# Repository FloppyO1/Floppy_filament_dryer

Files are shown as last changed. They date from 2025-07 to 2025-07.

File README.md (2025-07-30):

# Floppy Filament Dryer
Descrizione 1
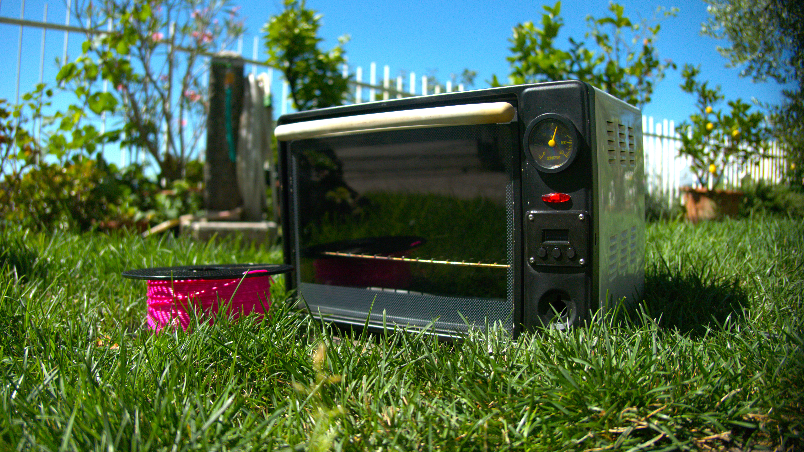
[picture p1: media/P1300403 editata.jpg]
Descrizione 2


This project is a controller board designed for a small electric oven, transforming it into a filament dryer for 3D printing. The controller allows precise temperature management, helping keep your filament dry and ready to use.

## Features

- Temperature control for effective filament drying
- Multiple materials presets
- Timer function
- Two custom material temp available
- Compatible with standard electric ovens
- Easy setup and integration

## YouTube Video

Watch it in action: [Filament Dryer Demo](https://youtu.be/55DRHrMC5Mg)

## License

This project is open source. See the LICENSE file for more details.

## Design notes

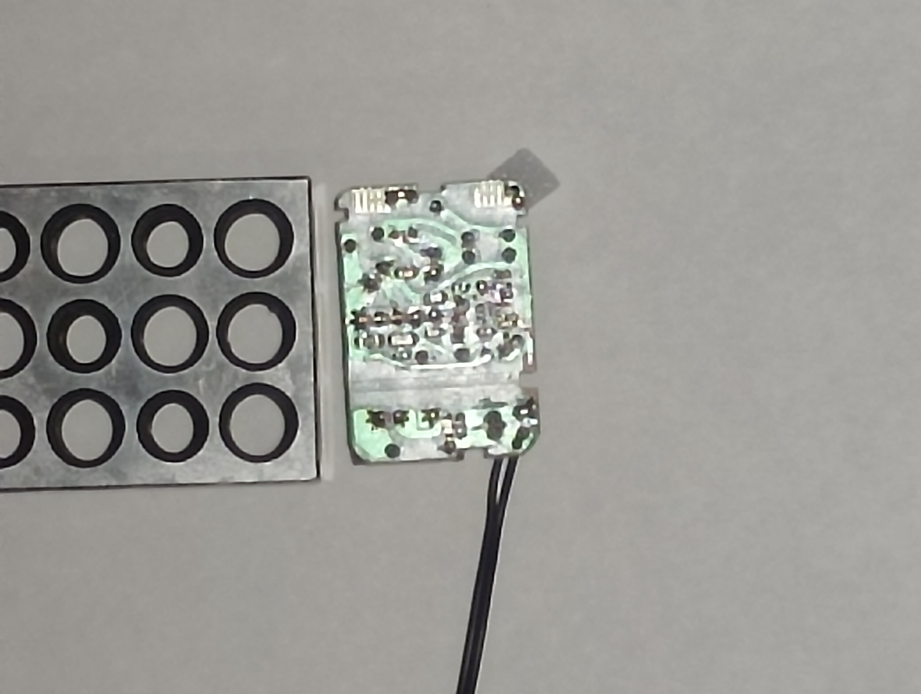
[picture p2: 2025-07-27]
CASE/case alimentatore 5v/ref image.jpg

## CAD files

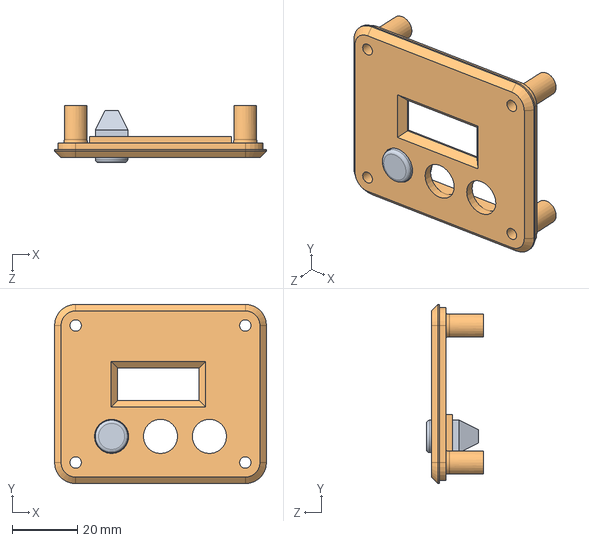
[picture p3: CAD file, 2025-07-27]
CASE/V1/Assieme.SLDASM
65.0 x 55.0 x 17.5 mm
Mascherina
button

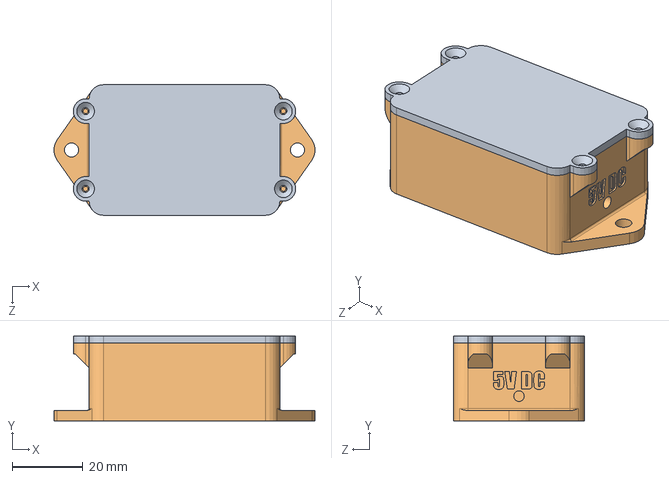
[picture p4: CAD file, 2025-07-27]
CASE/case alimentatore 5v/Assieme1.SLDASM
73.9 x 24.0 x 37.0 mm
CASE
COPERCHIO

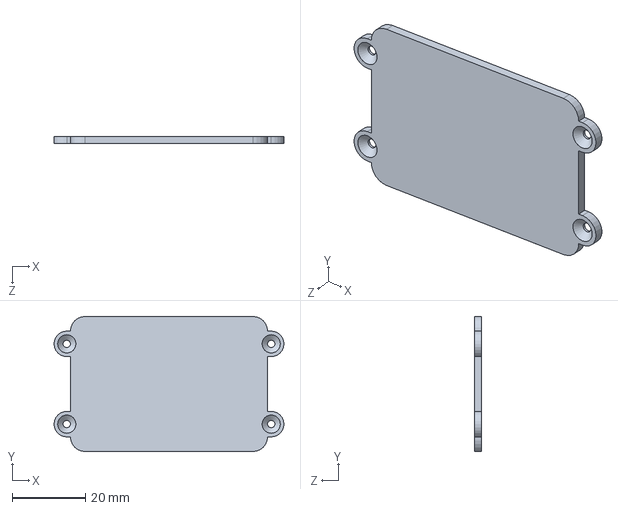
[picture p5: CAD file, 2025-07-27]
CASE/case alimentatore 5v/COPERCHIO.SLDPRT
63.0 x 37.0 x 2.00 mm

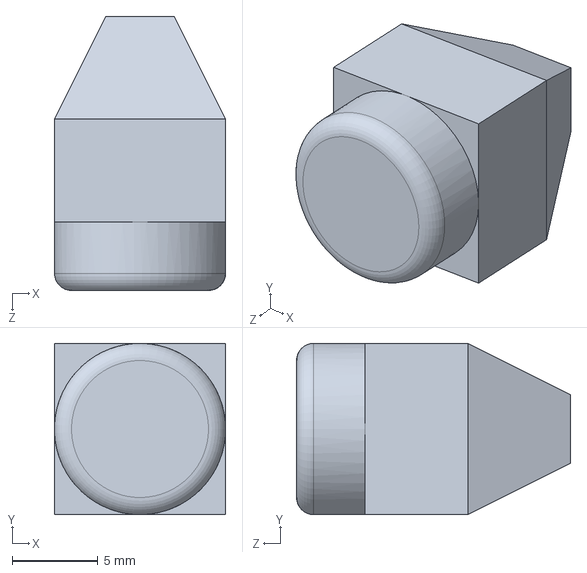
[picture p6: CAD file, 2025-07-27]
CASE/V1/button.SLDPRT
10.0 x 10.0 x 16.0 mm

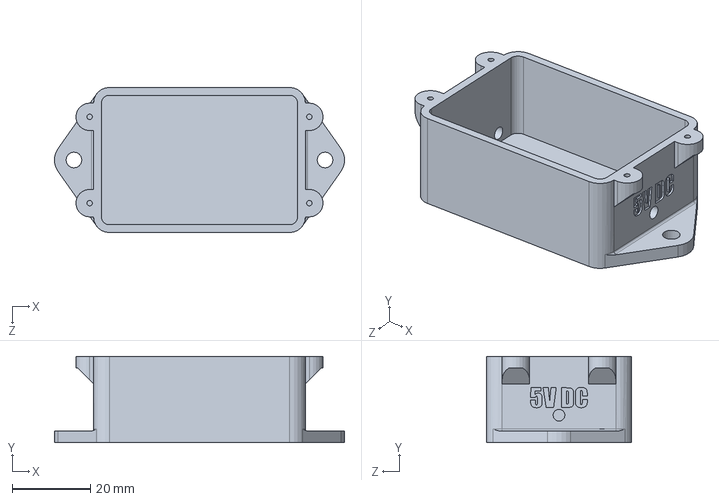
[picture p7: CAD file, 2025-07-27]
CASE/case alimentatore 5v/CASE.SLDPRT
73.9 x 22.0 x 37.0 mm

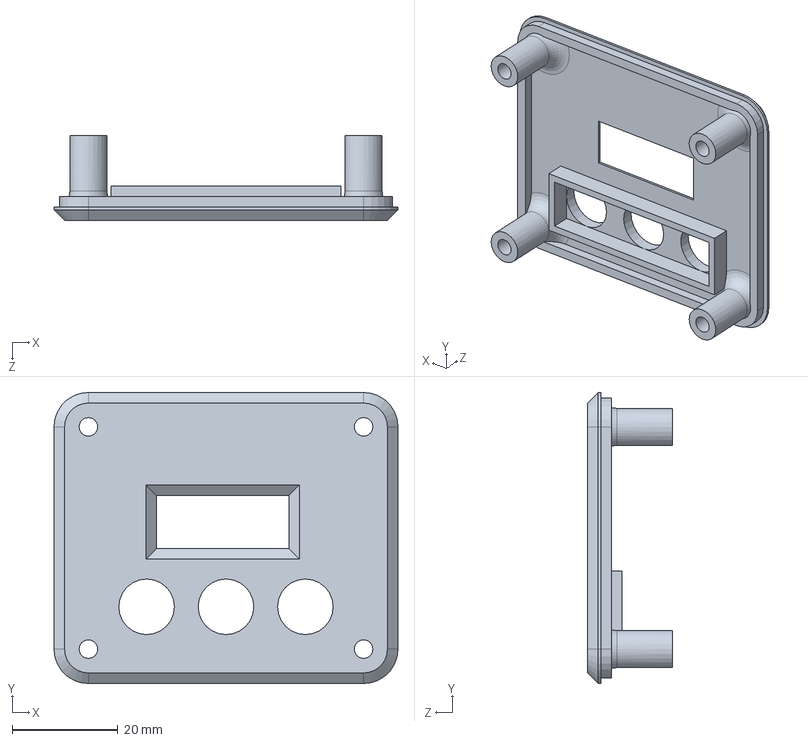
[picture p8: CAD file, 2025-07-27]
CASE/V1/Mascherina.SLDPRT
65.0 x 55.0 x 16.0 mm

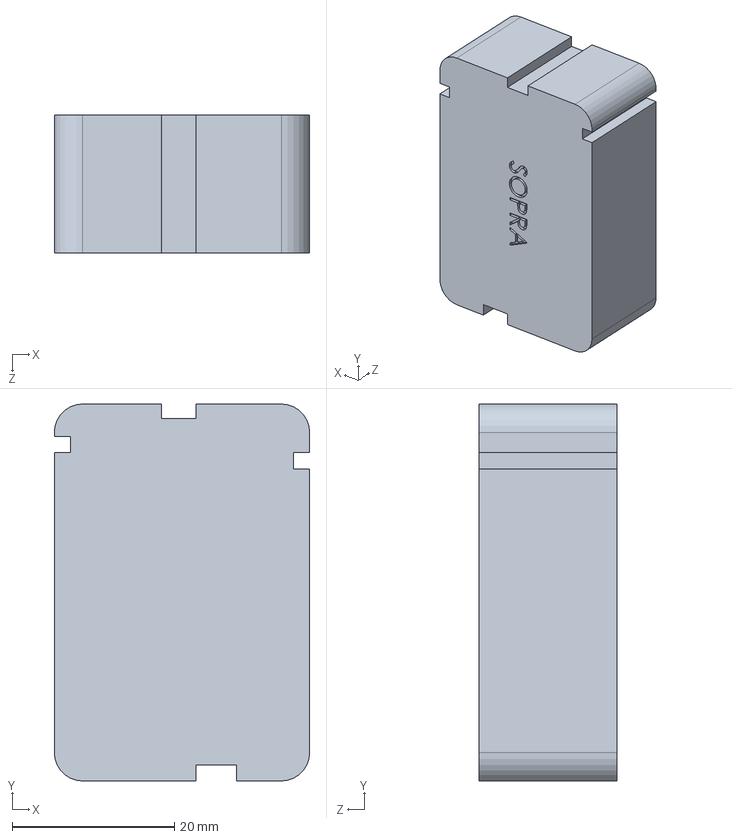
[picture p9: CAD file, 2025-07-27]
CASE/case alimentatore 5v/ingombro alimentatore.SLDPRT
31.5 x 46.5 x 17.0 mm

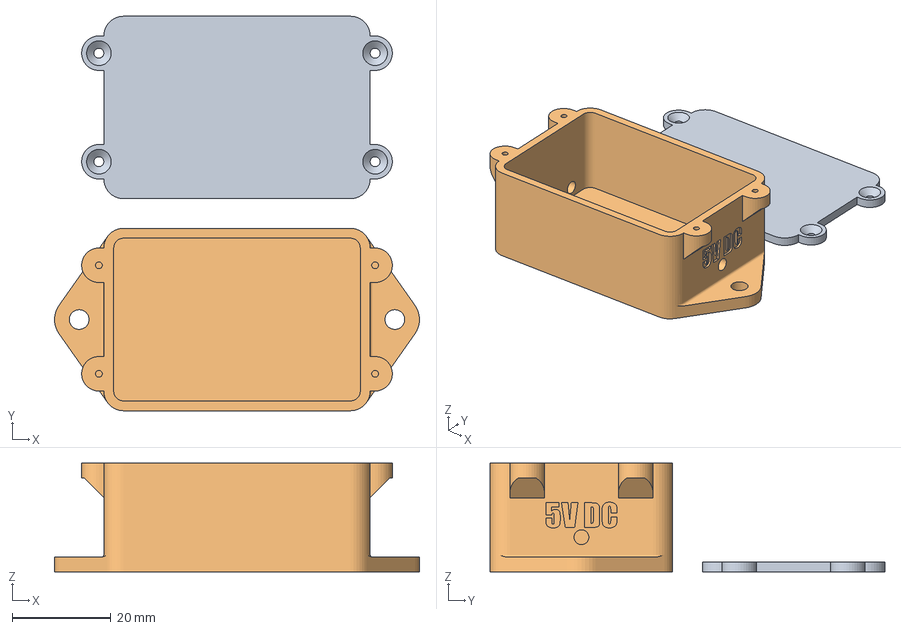
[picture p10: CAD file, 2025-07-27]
CASE/case alimentatore 5v/Scatoletta alimentatore 5v dc.3MF
74.0 x 80.0 x 22.0 mm

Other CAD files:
CASE/V1/Assieme.3MF

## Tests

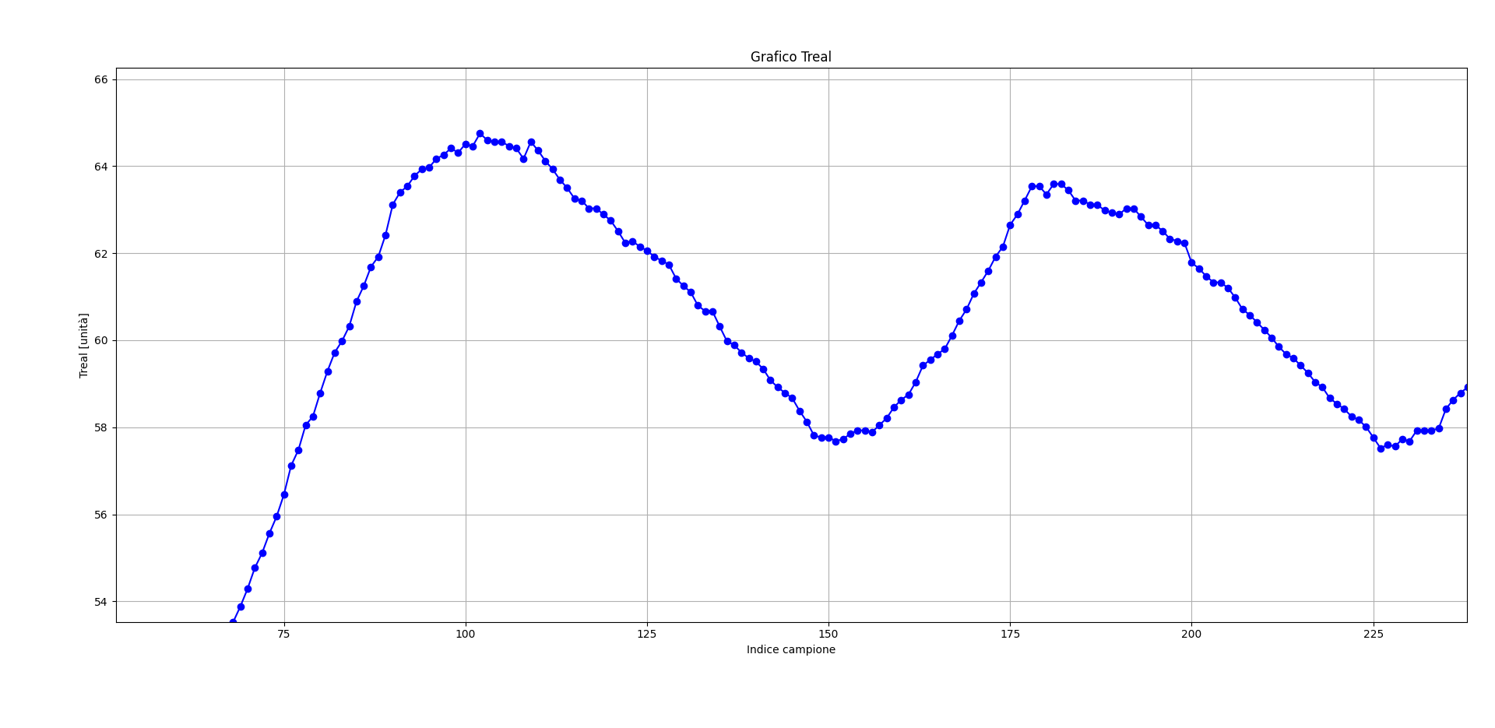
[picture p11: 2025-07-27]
SOFTWARE/Test autocalibrazione PID/Test 5/grafico zoom prime due oscillazioni.png

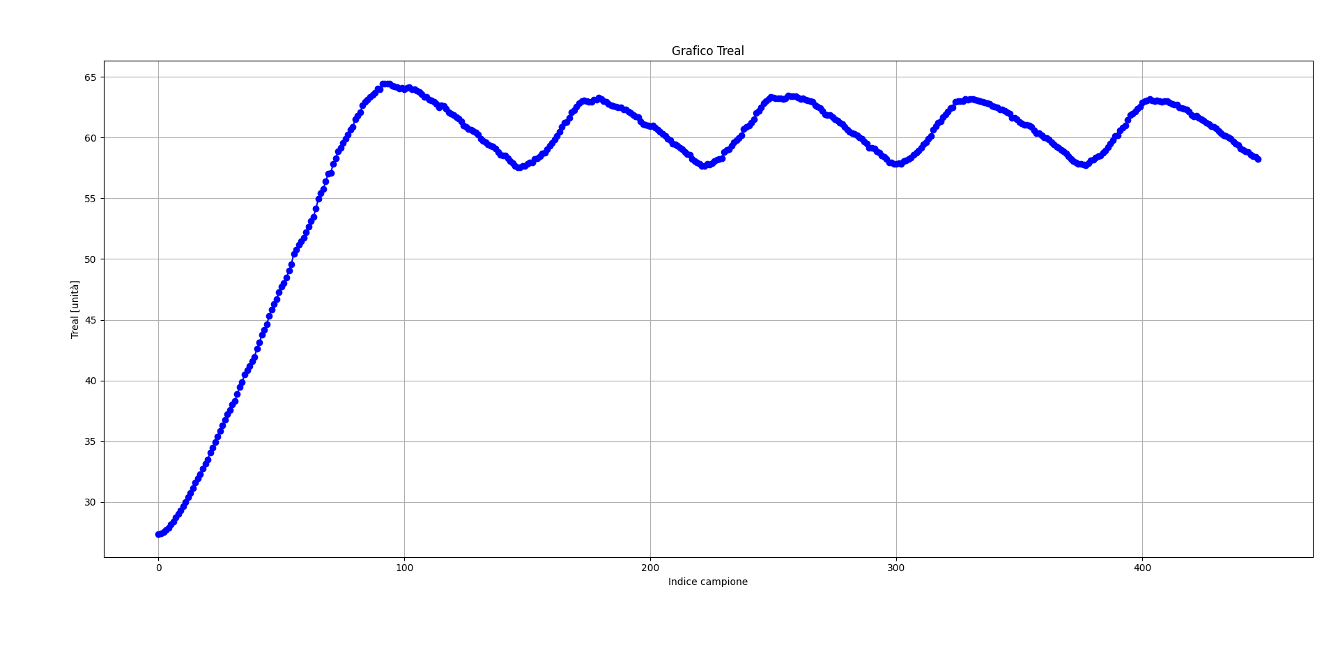
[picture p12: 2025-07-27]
SOFTWARE/Test autocalibrazione PID/Test 6/grafico completo.png

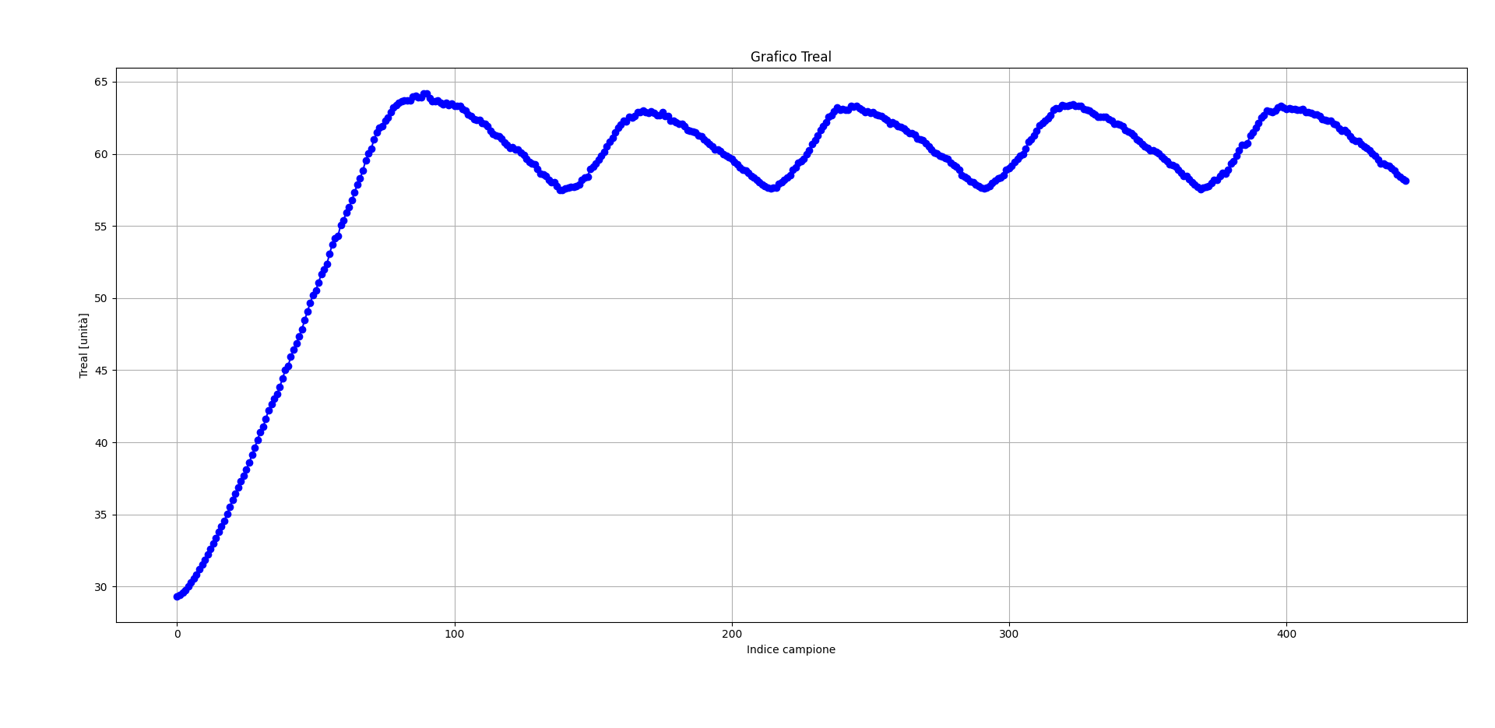
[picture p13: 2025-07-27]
SOFTWARE/Test autocalibrazione PID/Test 4/Figure_1.png

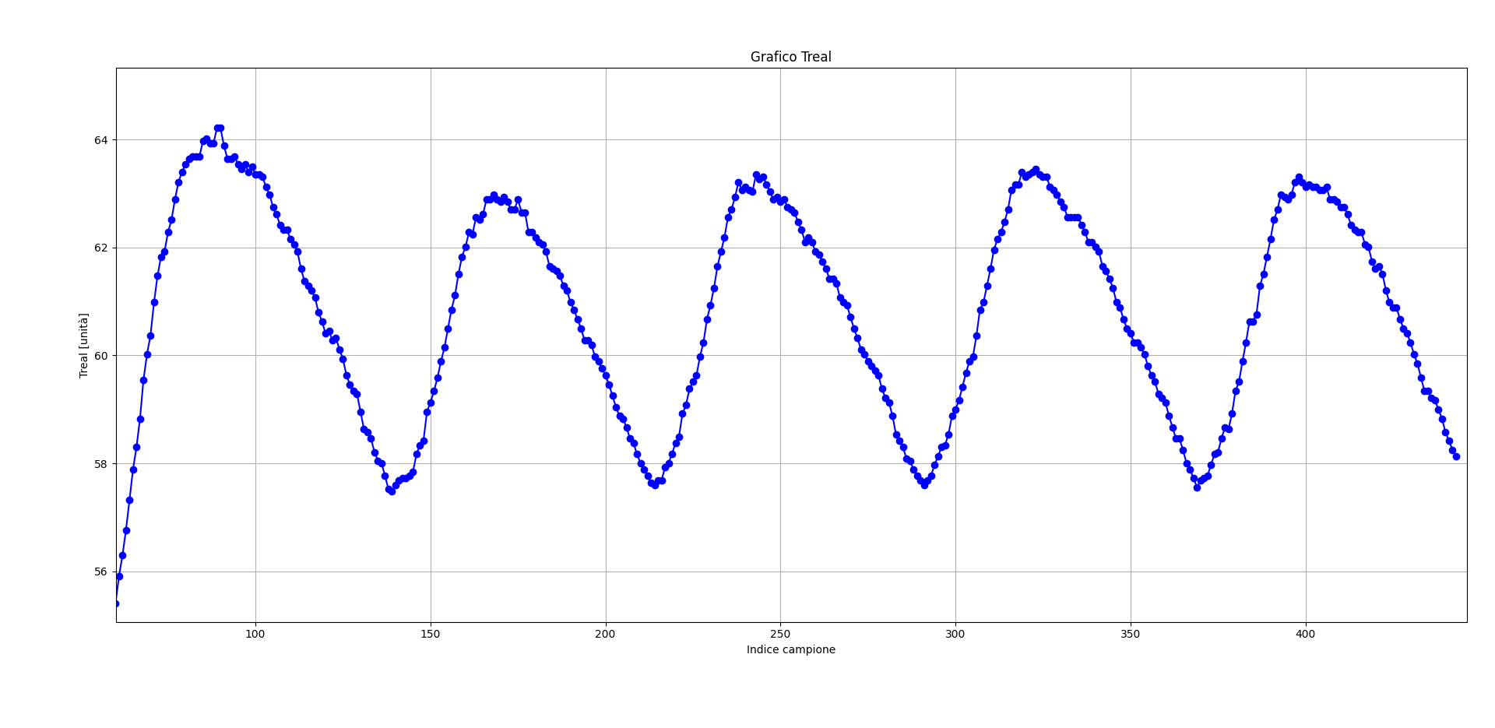
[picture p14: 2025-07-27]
SOFTWARE/Test autocalibrazione PID/Test 4/Figure_1 zoomed.png

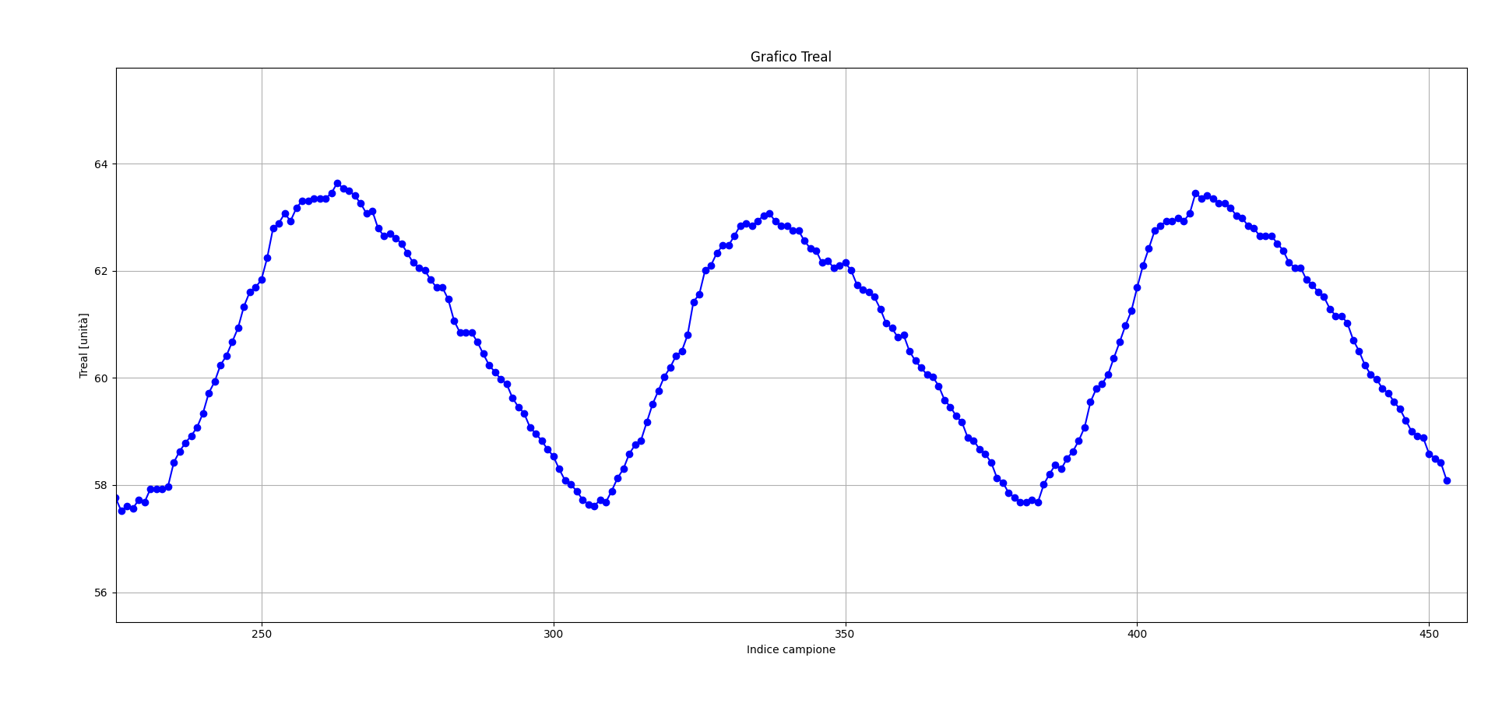
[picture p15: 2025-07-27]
SOFTWARE/Test autocalibrazione PID/Test 5/grafico zoom ultime 3 oscillazioni oscillazioni.png

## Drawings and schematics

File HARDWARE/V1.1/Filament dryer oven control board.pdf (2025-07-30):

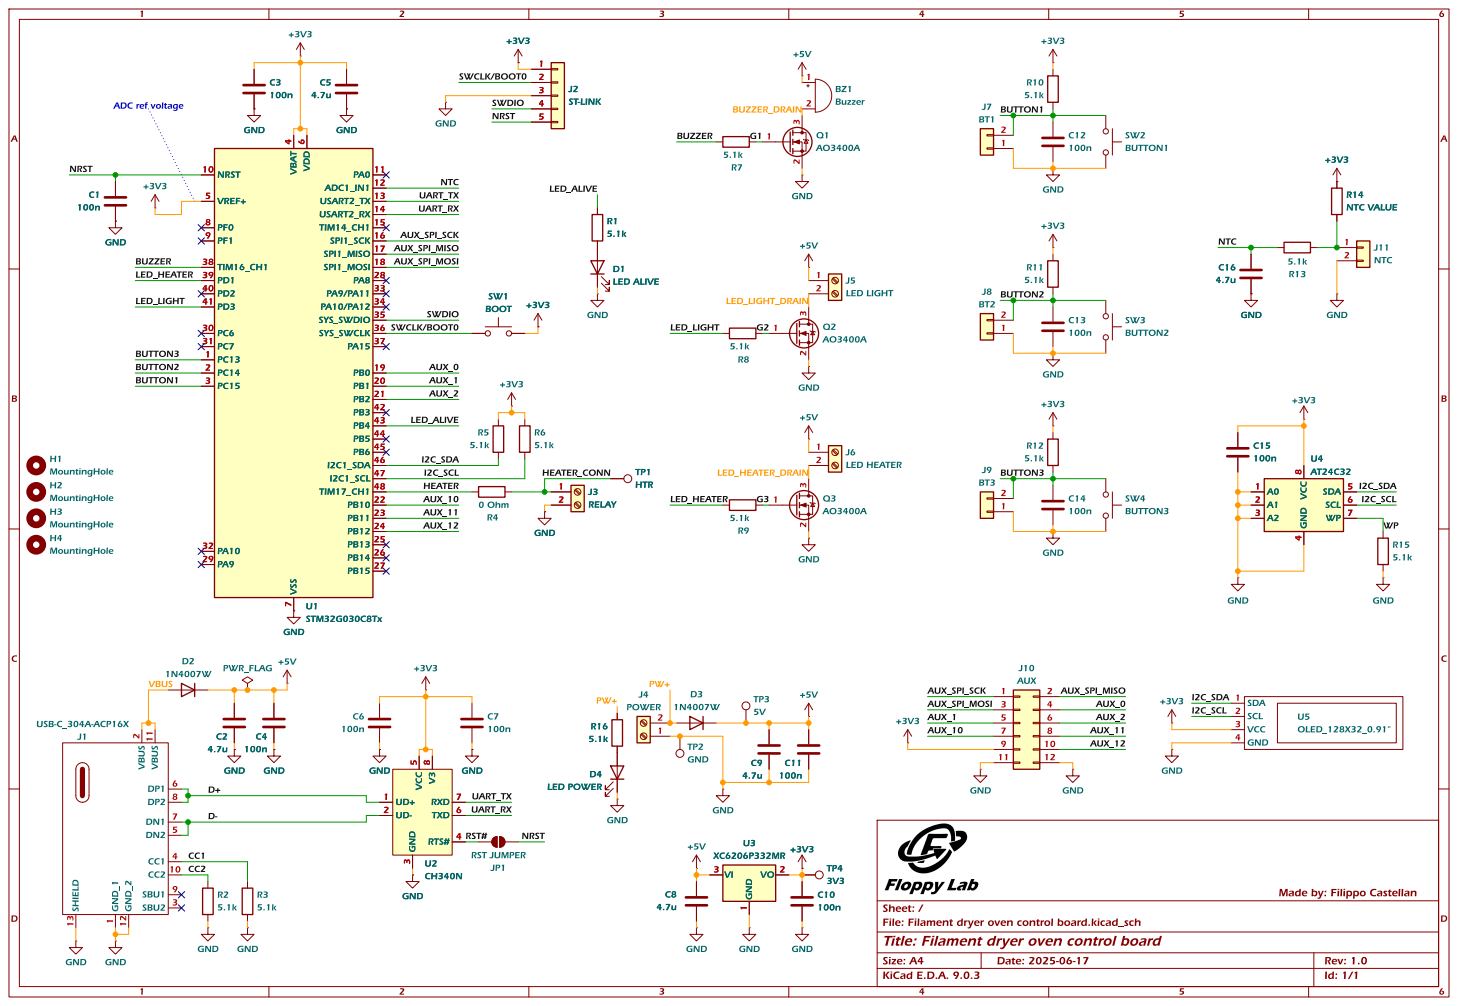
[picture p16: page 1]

Id: 1/1 Title: Filament dryer oven control board

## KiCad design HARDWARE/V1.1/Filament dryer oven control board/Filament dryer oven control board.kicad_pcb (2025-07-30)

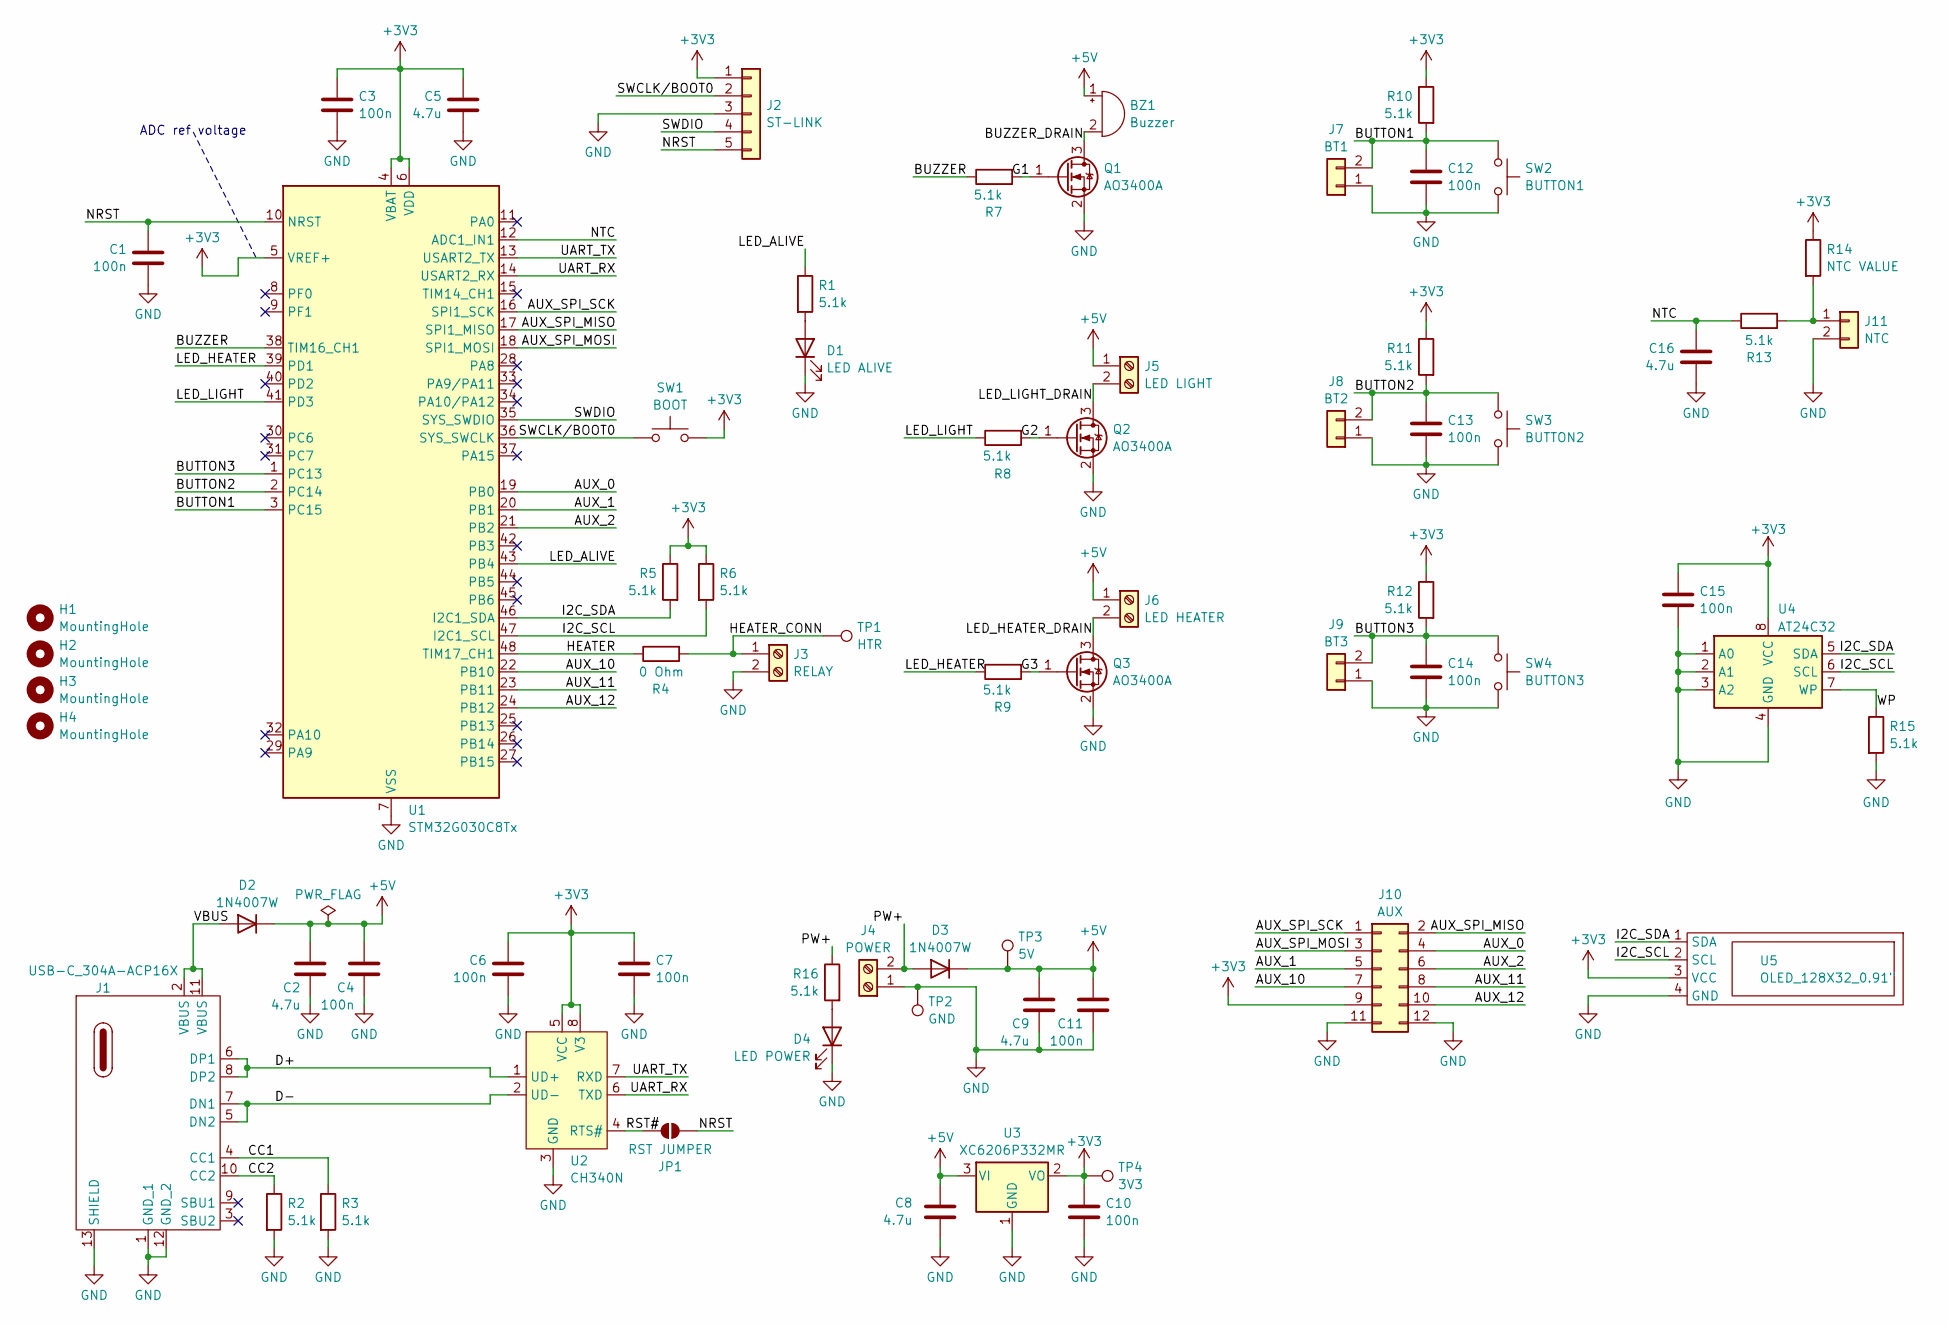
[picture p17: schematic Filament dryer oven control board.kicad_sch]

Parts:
BZ1: Buzzer; Buzzer_12x9.5RM7.6
C1, C3, C4, C6, C7, C10, C11, C12, C13, C14, C15: 100n; C_0805_2012Metric_Pad1.18x1.45mm_HandSolder
C2, C5, C8, C9, C16: 4.7u; C_0805_2012Metric_Pad1.18x1.45mm_HandSolder
D1: LED ALIVE; LED_0805_2012Metric_Pad1.15x1.40mm_HandSolder
D2, D3: 1N4007W; D_SOD-123F; LCSC C7528871
D4: LED POWER; LED_0805_2012Metric_Pad1.15x1.40mm_HandSolder
H1, H2, H3, H4: MountingHole; MountingHole_3.2mm_M3_Pad_Via
J1: USB-C_304A-ACP16X; USB_C_304A-ACP16X
J2: ST-LINK; PinHeader_1x05_P2.54mm_Vertical
J3: RELAY; TerminalBlock_bornier-2_P5.08mm
J4: POWER; TerminalBlock_bornier-2_P5.08mm
J5: LED LIGHT; TerminalBlock_bornier-2_P5.08mm
J6: LED HEATER; TerminalBlock_bornier-2_P5.08mm
J7: BT1; JST_XH_B2B-XH-A_1x02_P2.50mm_Vertical
J8: BT2; JST_XH_B2B-XH-A_1x02_P2.50mm_Vertical
J9: BT3; JST_XH_B2B-XH-A_1x02_P2.50mm_Vertical
J10: AUX; PinHeader_2x06_P2.54mm_Vertical
J11: NTC; JST_XH_B2B-XH-A_1x02_P2.50mm_Vertical
JP1: RST JUMPER; SolderJumper-2_P1.3mm_Open_RoundedPad1.0x1.5mm
Q1, Q2, Q3: AO3400A; SOT-23
R1, R2, R3, R5, R6, R7, R8, R9, R10, R11, R12, R13, R15, R16: 5.1k; R_0805_2012Metric_Pad1.20x1.40mm_HandSolder
R4: 0 Ohm; R_0805_2012Metric_Pad1.20x1.40mm_HandSolder
R14: NTC VALUE; R_0805_2012Metric_Pad1.20x1.40mm_HandSolder
SW1: BOOT; SW-SMD_TS24CA SMD BUTTO 90deg
SW2: BUTTON1; SW_SPST_SKQG_WithoutStem
SW3: BUTTON2; SW_SPST_SKQG_WithoutStem
SW4: BUTTON3; SW_SPST_SKQG_WithoutStem
TP1: HTR; TestPoint_THTPad_1.0x1.0mm_Drill0.5mm
TP2: GND; TestPoint_THTPad_1.0x1.0mm_Drill0.5mm
TP3: 5V; TestPoint_THTPad_1.0x1.0mm_Drill0.5mm
TP4: 3V3; TestPoint_THTPad_1.0x1.0mm_Drill0.5mm
U1: STM32G030C8Tx; LQFP-48_7x7mm_P0.5mm
U2: CH340N; SOP-8_3.9x4.9mm_P1.27mm
U3: XC6206P332MR; SOT-23-3
U4: AT24C32; SO-8_3.9x4.9mm_P1.27mm
U5: OLED_128X32_0.91"; PinSocket_1x04_P2.54mm_Vertical

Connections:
+3V3: C3.1, C5.1, C6.1, C7.1, C10.1, C15.1, J2.1, J10.9, R5.1, R6.1, R10.1, R11.1, R12.1, R14.1, SW1.2, TP4.1, U1.4 (VBAT), U1.5 (VREF+), U1.6 (VDD), U2.5 (VCC), U2.8 (V3), U3.2 (VO), U4.8 (VCC), U5.3 (VCC)
+5V: BZ1.1 (+), C2.1, C4.1, C8.1, C9.1, C11.1, D2.1 (K), D3.1 (K), J5.1, J6.1, TP3.1, U3.3 (VI)
/AUX_0: J10.4, U1.19 (PB0)
/AUX_1: J10.5, U1.20 (PB1)
/AUX_2: J10.6, U1.21 (PB2)
/AUX_10: J10.7, U1.22 (PB10)
/AUX_11: J10.8, U1.23 (PB11)
/AUX_12: J10.10, U1.24 (PB12)
/AUX_SPI_MISO: J10.2, U1.17 (SPI1_MISO)
/AUX_SPI_MOSI: J10.3, U1.18 (SPI1_MOSI)
/AUX_SPI_SCK: J10.1, U1.16 (SPI1_SCK)
/BUTTON1: C12.1, J7.2, R10.2, SW2.1, U1.3 (PC15)
/BUTTON2: C13.1, J8.2, R11.2, SW3.1, U1.2 (PC14)
/BUTTON3: C14.1, J9.2, R12.2, SW4.1, U1.1 (PC13)
/BUZZER: R7.1, U1.38 (TIM16_CH1)
/BUZZER_DRAIN: BZ1.2 (-), Q1.3 (D)
/CC1: J1.4 (CC1), R3.1
/CC2: J1.10 (CC2), R2.1
/D+: J1.6 (DP1), J1.8 (DP2), U2.1 (UD+)
/D-: J1.5 (DN2), J1.7 (DN1), U2.2 (UD-)
/G1: Q1.1 (G), R7.2
/G2: Q2.1 (G), R8.2
/G3: Q3.1 (G), R9.2
/HEATER: R4.1, U1.48 (TIM17_CH1)
/HEATER_CONN: J3.1, R4.2, TP1.1
/I2C_SCL: R6.2, U1.47 (I2C1_SCL), U4.6 (SCL), U5.2 (SCL)
/I2C_SDA: R5.2, U1.46 (I2C1_SDA), U4.5 (SDA), U5.1 (SDA)
/LED_ALIVE: R1.1, U1.43 (PB4)
/LED_HEATER: R9.1, U1.39 (PD1)
/LED_HEATER_DRAIN: J6.2, Q3.3 (D)
/LED_LIGHT: R8.1, U1.41 (PD3)
/LED_LIGHT_DRAIN: J5.2, Q2.3 (D)
/NRST: C1.1, J2.5, JP1.1 (A), U1.10 (NRST)
/NTC: C16.1, R13.1, U1.12 (ADC1_IN1)
/PW+: D3.2 (A), J4.2, R16.1
/RST#: JP1.2 (B), U2.4 (RTS#)
/SWCLK/BOOT0: J2.2, SW1.1, U1.36 (SYS_SWCLK)
/SWDIO: J2.4, U1.35 (SYS_SWDIO)
/UART_RX: U1.14 (USART2_RX), U2.6 (TXD)
/UART_TX: U1.13 (USART2_TX), U2.7 (RXD)
/VBUS: D2.2 (A), J1.2 (VBUS), J1.11 (VBUS)
/WP: R15.1, U4.7 (WP)
GND: C1.2, C2.2, C3.2, C4.2, C5.2, C6.2, C7.2, C8.2, C9.2, C10.2, C11.2, C12.2, C13.2, C14.2, C15.2, C16.2, D1.1 (K), D4.1 (K), J1.1 (GND_1), J1.12 (GND_2), J1.13 (SHIELD), J2.3, J3.2, J4.1, J7.1, J8.1, J9.1, J10.11, J10.12, J11.2, Q1.2 (S), Q2.2 (S), Q3.2 (S), R2.2, R3.2, R15.2, SW2.2, SW3.2, SW4.2, TP2.1, U1.7 (VSS), U2.3 (GND), U3.1 (GND), U4.1 (A0), U4.2 (A1), U4.3 (A2), U4.4 (GND), U5.4 (GND)
unnamed: D1.2 (A), R1.2
unnamed: D4.2 (A), R16.2
unnamed: J11.1, R13.2, R14.2

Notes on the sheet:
ADC ref voltage

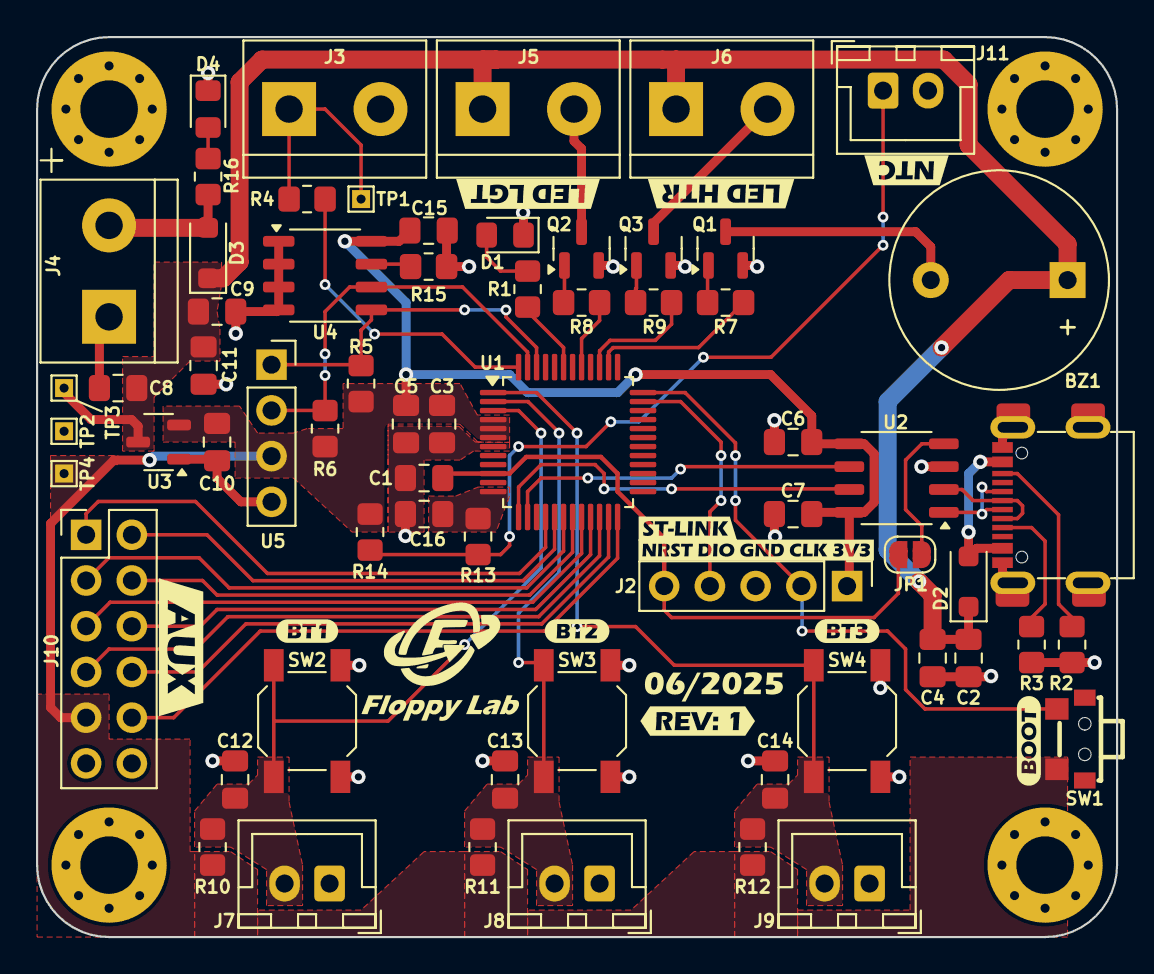
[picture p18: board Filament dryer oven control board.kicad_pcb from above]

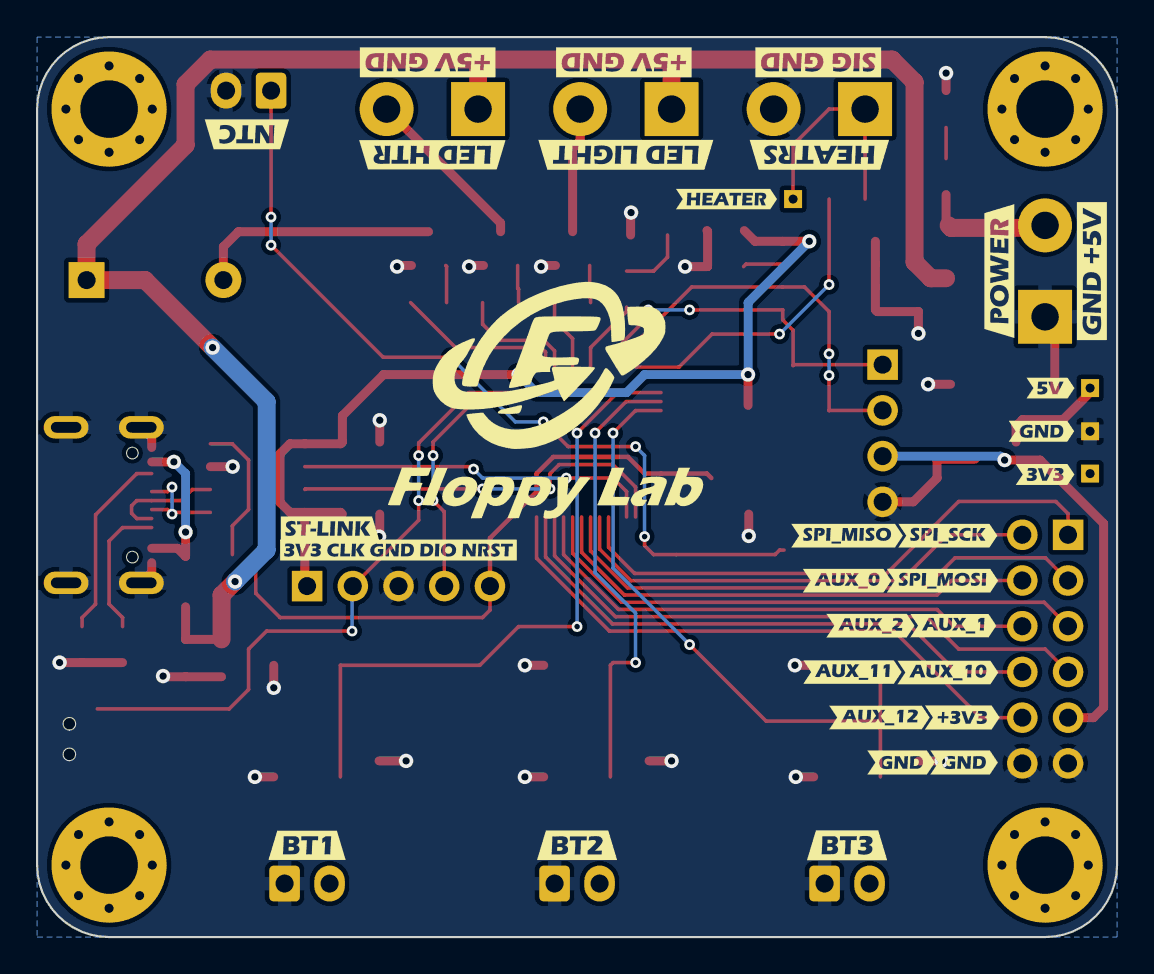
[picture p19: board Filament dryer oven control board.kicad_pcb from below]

Board: 2 copper layers, 60.0 x 50.0 mm, 111 parts (30 on the bottom side), 46 nets.

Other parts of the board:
kibuzzard-6853DD8E: G***; kibuzzard-6853DD8E
kibuzzard-6853DD65: G***; kibuzzard-6853DD65
kibuzzard-6853DD93: G***; kibuzzard-6853DD93
kibuzzard-6853DDBD, kibuzzard-6853DDBD#2: G***; kibuzzard-6853DDBD
kibuzzard-6853DE43: G***; kibuzzard-6853DE43
kibuzzard-6853DE79: G***; kibuzzard-6853DE79
kibuzzard-6853DEDF: G***; kibuzzard-6853DEDF
kibuzzard-6853DFAB, kibuzzard-6853DFAB#2: G***; kibuzzard-6853DFAB
kibuzzard-6853DFD3: G***; kibuzzard-6853DFD3
kibuzzard-6853E9B3, kibuzzard-6853E9B3#2: G***; kibuzzard-6853E9B3
kibuzzard-6853E9C2: G***; kibuzzard-6853E9C2
kibuzzard-6853E9F3: G***; kibuzzard-6853E9F3
kibuzzard-6853E92D: G***; kibuzzard-6853E92D
kibuzzard-6853E947: G***; kibuzzard-6853E947
kibuzzard-6853E998: G***; kibuzzard-6853E998
kibuzzard-6853EA0A: G***; kibuzzard-6853EA0A
kibuzzard-6853EB5D: G***; kibuzzard-6853EB5D
kibuzzard-6853EB86: G***; kibuzzard-6853EB86
kibuzzard-6853EBAF: G***; kibuzzard-6853EBAF
kibuzzard-6853EBB8: G***; kibuzzard-6853EBB8
kibuzzard-6853EBDD: G***; kibuzzard-6853EBDD
kibuzzard-6853EBE6: G***; kibuzzard-6853EBE6
kibuzzard-6853EBF5: G***; kibuzzard-6853EBF5
kibuzzard-6853EC00: G***; kibuzzard-6853EC00
kibuzzard-6853EC1A: G***; kibuzzard-6853EC1A
kibuzzard-6853EC51: G***; kibuzzard-6853EC51
kibuzzard-6853EC60, kibuzzard-6853EC60#2: G***; kibuzzard-6853EC60
kibuzzard-6853ECA3: G***; kibuzzard-6853ECA3
kibuzzard-6853ECB2: G***; kibuzzard-6853ECB2
kibuzzard-6853ECDA: G***; kibuzzard-6853ECDA
kibuzzard-6853EE5A: G***; kibuzzard-6853EE5A
kibuzzard-6853EFA6: G***; kibuzzard-6853EFA6
kibuzzard-6853EFB4: G***; kibuzzard-6853EFB4
kibuzzard-6853EFC3: G***; kibuzzard-6853EFC3
kibuzzard-6853EFD6: G***; kibuzzard-6853EFD6
kibuzzard-6853F23E: G***; kibuzzard-6853F23E
kibuzzard-6889D489: G***; kibuzzard-6889D489
kibuzzard-6889D529: G***; kibuzzard-6889D529

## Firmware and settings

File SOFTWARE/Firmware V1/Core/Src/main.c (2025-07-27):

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
/* Includes ------------------------------------------------------------------*/
#include "main.h"
#include "adc.h"
#include "i2c.h"
#include "tim.h"
#include "usart.h"
#include "gpio.h"

/* USER CODE BEGIN Includes */
#include <string.h>

#include "MyCode/config.h"
#include "Libraries/Display/ssd1306.h"
#include "MyCode/display.h"
#include "Libraries/temperature.h"
#include "MyCode/materials.h"
#include "MyCode/buttons.h"
#include "MyCode/buzzer.h"
#include "MyCode/pid.h"
#include "MyCode/settings.h"
/* USER CODE END Includes */


/* USER CODE BEGIN PV */
/* TIMERS */
uint32_t timerLedAlive = 0;
uint32_t timerDisplayUpdate = 0;
uint32_t timerTempRead = 0;
uint32_t timerTimer = 10000; // not zero to make the first popup at the startup of the device

/* MENUS */
volatile uint8_t currentMenu = MENU_HOME; // active menu (starts with the home menu)

/* MATERIALS */
volatile uint8_t currentMaterialID;

/* TIMER */
volatile uint16_t minutesLeft = 0;	// 2h10m

/* TEMPERATURE CONTROL */
volatile float kp = 20.0f;
volatile float ki = 1.0f;
volatile float kd = 0.2f;
uint8_t runPid = 0;	// 1 if pid must be run
volatile uint8_t duty = 0;
volatile uint8_t heaterOn = 0;
/* USER CODE END PV */

void SystemClock_Config(void);
/**
 * @brief  The application entry point.
 * @retval int
 */
int main(void) {

	/* MCU Configuration--------------------------------------------------------*/

	/* Reset of all peripherals, Initializes the Flash interface and the Systick. */
	HAL_Init();

	/* Configure the system clock */
	SystemClock_Config();

	/* Initialize all configured peripherals */
	MX_GPIO_Init();
	MX_ADC1_Init();
	MX_I2C1_Init();
	MX_USART2_UART_Init();
	MX_TIM16_Init();
	MX_TIM3_Init();
	MX_TIM17_Init();
	/* USER CODE BEGIN 2 */
	/* -------------------------------- INITIALIZATIONS -------------------------------- */
	/* DISPLAY INIT*/
	ssd1306_Init();
	/* ADC INIT */
	HAL_Delay(50);
	HAL_ADCEx_Calibration_Start(&hadc1);
	HAL_Delay(50);
	HAL_ADC_Init(&hadc1);
	/* BUTTONS INIT */
	initButtons();
	/* UART INIT */
	HAL_UART_Init(&huart2);
	/* MATERIALS */
	MATERIAL_initMaterials();
	currentMaterialID = MATERIAL_ID_PLA;
	/* BUZZER INIT */
	HAL_TIM_Base_Init(&htim16);
	HAL_TIM_PWM_Start(&htim16, TIM_CHANNEL_1);
	TIM16->CCR1 = 0;
	/* HEATER INIT */
	HAL_TIM_Base_Init(&htim17);
	HAL_TIM_Base_Start_IT(&htim17);
	HAL_TIM_PWM_Start_IT(&htim17, TIM_CHANNEL_1);
	setDuty(0);
	/* INIT 500ms PID TIMER */
	HAL_TIM_Base_Init(&htim3);
	HAL_TIM_Base_Start_IT(&htim3);
	/* LOAD SETTINGS FROM EEPROM */
	HAL_Delay(2000);	// otherwise the serial debug will not work
	if (read_byte_eeprom(EEPROM_ISFIRSTBOOT_ADDRESS) != FIRST_TIME_EEPROM_VALUE) {// if this is the first time eeprom is written or is empty, write the default settings
		printString("First boot, or eeprom was empty\n");
		storeSettingsToEeprom(kp, ki, kd);	// store settings

		loadSettingsFromEeprom(&kp, &ki, &kd);	// than read settings for a check
		uint8_t message[100];
		sprintf(message, "Stored default kp, ki, kd value (%f, %f, %f)\n", kp, ki, kd);
		printString(message);
		write_byte_eeprom(EEPROM_ISFIRSTBOOT_ADDRESS, FIRST_TIME_EEPROM_VALUE);
		printString("Now the eeprom was initialized the first time\n");
	} else {
		loadSettingsFromEeprom(&kp, &ki, &kd);
		uint8_t message[100];
		sprintf(message, "Loaded kp, ki, kd value from eeprom (%f, %f, %f)\n", kp, ki, kd);
		printString(message);
	}

	/* USER CODE END 2 */

	/* Infinite loop */
	/* USER CODE BEGIN WHILE */
	while (1) {
		/* BUTTON CODE */
		uint8_t relase = BUTTONS_tick();

		/* TEMPERATURE CODE */
		float realTemp = getTemperature();	// caluclate the real temp

		/* TIMER CHECK */
		if (minutesLeft <= 0) {
			minutesLeft = 0;
			heaterOn = 0;
			// make some noise, repeat for some time than do nothing !!! NOISE MADE ON THE PERIOD ROUTIN !!!
		} else {
			heaterOn = 1;
		}

		if (heaterOn) {
			HAL_GPIO_WritePin(LED_LIGHT_GPIO_Port, LED_LIGHT_Pin, 1);	// turn on the light
			if (runPid) {	// run the pid control every 500ms
				duty = pid_control(kp, ki, kd, MATERIAL_getMaterialTargetTemp(currentMaterialID), realTemp, UINT8_MAX);
				setDuty(duty);
				runPid = 0;
			}
		} else {
			HAL_GPIO_WritePin(LED_LIGHT_GPIO_Port, LED_LIGHT_Pin, 0); // turn off the light
			duty = 0;
			setDuty(duty);
		}

		/* USER CODE END WHILE */

		/* USER CODE BEGIN 3 */

		/* DISPLAY UPDATE */
		if (HAL_GetTick() - timerTimer >= MINUTES_STEP * 60 * 1000) {
			//if (HAL_GetTick() - timerTimer >= 10000) {// decrement every 10seconds for testing
			if (minutesLeft - MINUTES_STEP == 0 || minutesLeft <= 0) {
				minutesLeft = 0;
				// display the popup
				ssd1306_Fill(Black);
				DISPLAY_PrintStrLarge("TIME OVER", 14, 0);
				DISPLAY_PrintStrMedium("Set new time!", 18, 22);
				ssd1306_UpdateScreen();
				// make some sound
				BUZZER_shortPressBeep();
				BUZZER_shortPressBeep();
				HAL_Delay(200);
				BUZZER_shortPressBeep();
				BUZZER_shortPressBeep();
				HAL_Delay(200);
				BUZZER_shortPressBeep();
				BUZZER_shortPressBeep();
				HAL_Delay(200);
				BUZZER_shortPressBeep();
				BUZZER_shortPressBeep();
				HAL_Delay(1000);
				BUZZER_shortPressBeep();
				BUZZER_shortPressBeep();
				HAL_Delay(200);
				BUZZER_shortPressBeep();
				BUZZER_shortPressBeep();
				HAL_Delay(200);
				BUZZER_shortPressBeep();
				BUZZER_shortPressBeep();
				HAL_Delay(200);
				BUZZER_shortPressBeep();
				BUZZER_shortPressBeep();
				HAL_Delay(1000);
			} else {
				minutesLeft -= MINUTES_STEP;
				BUZZER_longPressBeep();
			}
			timerTimer = HAL_GetTick();
		}
		if (HAL_GetTick() - timerDisplayUpdate >= 1000 / DISPLAY_FPS) {
			DISPLAY_drawMenu(currentMenu, currentMaterialID, realTemp, minutesLeft, duty);

			if (relase) {
				DISPLAY_PrintStrSmall("RELASE", 50, 24);
			}

			ssd1306_UpdateScreen();
			timerDisplayUpdate = HAL_GetTick();
		}
		/* LED ALIVE BLINK */
		if (HAL_GetTick() - timerLedAlive >= LED_ALIVE_FLASHING_PERIOD / 2) {
			HAL_GPIO_TogglePin(LED_ALIVE_GPIO_Port, LED_ALIVE_Pin);
			timerLedAlive = HAL_GetTick();
		}
	}
	/* USER CODE END 3 */
}

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
/* USER CODE BEGIN 4 */
void HAL_TIM_PeriodElapsedCallback(TIM_HandleTypeDef *htim) {
	if (htim == &htim3) {
		runPid = 1;
	}
	if (htim == &htim17) {
		if (duty != 0 && currentMenu != MENU_AUTOCAL_1) {
			HAL_GPIO_WritePin(LED_HEATING_GPIO_Port, LED_HEATING_Pin, 1);
		}
	}
}

void HAL_TIM_PWM_PulseFinishedCallback(TIM_HandleTypeDef *htim) {
	if (htim == &htim17) {
		if (currentMenu != MENU_AUTOCAL_1) {
			HAL_GPIO_WritePin(LED_HEATING_GPIO_Port, LED_HEATING_Pin, 0);
		}

	}
}
void printString(char *str) {
	HAL_UART_Transmit(&huart2, str, strlen(str), HAL_MAX_DELAY);
}
/* USER CODE END 4 */
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


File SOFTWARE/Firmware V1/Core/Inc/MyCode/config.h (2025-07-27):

/*
 * config.h
 *
 *  Created on: Jul 10, 2025
 *      Author: Filippo Castellan
 */

#ifndef INC_MYCODE_CONFIG_H_
#define INC_MYCODE_CONFIG_H_



/* GENERAL */
#define LED_ALIVE_FLASHING_PERIOD 500

/* MATERIALS */
#define TEMPERATURE_STEP 5
#define MINIMUM_TEMPERATURE 20
#define MAXIMUM_TEMPERATURE 95

/* TIMER */
#define MINUTES_STEP 10
#define MAXIMUM_HOURS 120


/* DISPLAY */
#define DISPLAY_FPS 10
#define STATUS_CHANGE_TIME 5000

/* TEMP READ */
#define NTC_NOMINAL 100000
#define RBALANCE 100000.0
#define RESOLUTION 4096.0
#define BETA 3950.0
#define TEMPERATURE_READ_INTERVAL 200

/* PID AUTOCALIBRATION */
#define MAX_READINGS_NUMBER 2000
#define MAX_MIN_FINDER_WINDOW 20
#define INITIAL_OSCILLATION_TO_SKIP 1
#define READINGS_PERIOD 2000
#define PID_AUTOCAL_CYCLES 8
#define PID_AUTOCAL_TEMPERATURE 70.0f
#define PID_AUTOTUNE_HYSTERESIS 2.0f

/* EEPROM */
#define FIRST_TIME_EEPROM_VALUE 79	// change this value if you want to re-inizialize eeprom (ranfe: 0-255)

/* BUTTONS */
#define SHORT_PRESS_TIME 50
#define LONG_PRESS_TIME 1000

/* BUZZER */
#define LOUDNESS_PERCENTAGE 50

#endif /* INC_MYCODE_CONFIG_H_ */

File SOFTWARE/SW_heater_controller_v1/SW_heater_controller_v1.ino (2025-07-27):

// HEATER
#define mosfet_pin PA6
#define led PC15

// NTC
#define ntc_pin PA0                // Pin,to which the voltage divider is connected
#define vd_power_pin PA4           // 5V for the voltage divider
#define nominal_resistance 150000  // Nominal resistance at 25⁰C
#define nominal_temeprature 25     // temperature for nominal resistance (almost always 25⁰ C)
#define samplingrate 5             // Number of samples
#define beta 3950                  // The beta coefficient or the B value of the thermistor (usually 3000-4000) check the datasheet for the accurate value.
#define Rref 100520                // Value of  resistor used for the voltage divider
int samples = 10;                  // array to store the samples

void setup(void) {
  pinMode(mosfet_pin, OUTPUT);
  pinMode(led, OUTPUT);
  pinMode(ntc_pin, INPUT);
  pinMode(vd_power_pin, OUTPUT);
  // Serial.setRx(PA_10);
  // Serial.setTx(PA_9);
  Serial.begin(115200);  // initialize serial communication at a baud rate of 9600
  analogReadResolution(12);
  analogWriteFrequency(5);
}

#define error_ADC 0

int target_temp = 55;
#define KP 30
int time1 = 0;

void loop(void) {
  // int incomingByte = 0;  // for incoming serial data
  // if (Serial.available() > 0) {
  //   // read the incoming byte:
  //   incomingByte = Serial.read();
  //   target_temp = incomingByte;
  //   // say what you got:
  //   Serial.print("Temp setted to: ");
  //   Serial.println(incomingByte, DEC);
  // }


  if (millis() - time1 >= 500) {
    int real_temp = getTemperature(samples);
    Serial.println(real_temp);
    if (target_temp > real_temp) {
      digitalWrite(led, 1);
      int e = target_temp - real_temp;
      e = e * KP;
      if (e > 255) e = 255;
      analogWrite(mosfet_pin, e);
    } else {
      analogWrite(mosfet_pin, 0);
    }
    time1 = millis();
  }
}


float getTemperature(uint8_t readings) {
  uint8_t i;
  float average;
  samples = 0;
  // take voltage readings from the voltage divider
  digitalWrite(vd_power_pin, HIGH);
  for (i = 0; i < samplingrate; i++) {
    samples += analogRead(ntc_pin) + error_ADC;
    delay(10);
  }
  digitalWrite(vd_power_pin, LOW);
  average = 0;
  average = samples / samplingrate;

  // Calculate NTC resistance
  average = 4096 / average - 1;
  average = Rref / average;
  float temperature;
  temperature = average / nominal_resistance;           // (R/Ro)
  temperature = log(temperature);                       // ln(R/Ro)
  temperature /= beta;                                  // 1/B * ln(R/Ro)
  temperature += 1.0 / (nominal_temeprature + 273.15);  // + (1/To)
  temperature = 1.0 / temperature;                      // Invert
  temperature -= 273.15;                                // convert absolute temp to C
  return temperature - 13;
}

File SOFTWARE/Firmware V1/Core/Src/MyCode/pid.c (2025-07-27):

/*
 * pid.c
 *
 *  Created on: Jul 12, 2025
 *      Author: Filippo Castellan
 */

#include <stdio.h>
#include "tim.h"
#include "MyCode/pid.h"
#include "Libraries/temperature.h"
#include "MyCode/display.h"
#include "Libraries/Display/ssd1306.h"
#include "MyCode/config.h"

extern volatile uint8_t currentMenu;
extern uint32_t timerTimer;

void setDuty(uint8_t duty) {
	TIM17->CCR1 = duty;
}

uint8_t pid_control(float kp, float ki, float kd, float target, float real, uint16_t dutymax) {
	static float integral = 0.0f;
	static float previous_error = 0.0f;
	const float dt = 0.5f; // interval of (500 ms)

	float error = target - real;
	integral += error * dt;
	float derivative = (error - previous_error) / dt;
	previous_error = error;
//	if(error >= 10) {	// for a more rapid response and minor oscillation
//		kp *= 3;
//	}
//	if (error >= 10) {// to keep the overshoot small and have long term error reduced
//		integral = 0.0f;	// reset the integral value if the error is more than 10 deg
//	}

	float output = kp * error + ki * integral + kd * derivative;

	if (output > dutymax) {	// do not increment the integral term if the duty is already at max value. To prevent integral wind-up
		integral -= error * dt;
		output = kp * error + ki * integral + kd * derivative;
	}

// convert the range of the duty obtained
	if (output < 0)
		output = 0;
	if (output > dutymax)
		output = dutymax;

// for serial debug
	uint8_t str[100];
	sprintf(str, "kpe: %0.2f\tkie: %0.2f\tkde: %0.2f\tout: %0.2f\n", kp * error, ki * integral, kd * error, output);
	printString(str);

	return (uint8_t) output;
}

/*
 * THIS IS A BLOCKING FUNCTION, ONLY AT THE END OF IT THE PROGRAM EXECUTION CAN CONTINUE
 */
void PIDautoCal(float tempTarget, float hysteresis, uint8_t cycles, float *kp, float *ki, float *kd) { // bang-bang Ziegler-Nicloas PID auto calibration
	uint8_t str[50];
	printString("START PID AUTOTUNE PROCESS...\n");

	uint32_t timer1 = HAL_GetTick(); // for 'millis()' non blocking application during the steps loop
	uint16_t temps[MAX_READINGS_NUMBER];	// used for storing temp measurements. With one measure every seconds it can hold ~16min should be enough
	uint16_t nextTempsIndex = 0;

	/*	STEP 1
	 *  Make the system oscillating on its natural frequency.
	 *  1. Heating until Treal > Ttarget + hysteresis
	 *  2. Let the system cool down until reach Treal < Ttarget - hysteresis
	 *  3. Repeat from the point n 1 for 'repetitions' times
	 *  During this steps the temperature value are stored for the future max, min and period calculations
	 */
	uint8_t cycleNumber = 0;
	uint8_t turnedOn = 0;
	while (1) {
		// heating controll
		float Treal = getTemperature();
		HAL_GPIO_WritePin(LED_HEATING_GPIO_Port, LED_HEATING_Pin, turnedOn);
		if (Treal < tempTarget - hysteresis && !turnedOn) {	// turn on the heater
			setDuty(UINT8_MAX);
			cycleNumber++;	// start next cycle
			turnedOn = 1;
			// serial debug
			sprintf(str, "New cycle began, cycle number %d\n", cycleNumber);
			printString(str);
		}
		if (Treal > tempTarget + hysteresis && turnedOn) {	// turn off the heater
			setDuty(0);
			turnedOn = 0;
		}

		if (HAL_GetTick() - timer1 >= READINGS_PERIOD) { // repeat what's inside every 2 second
			// reset the timer
			timer1 = HAL_GetTick();
			// read temp and store into the array
			storeNewTemp(Treal, &nextTempsIndex, temps);
			// serial debug
			sprintf(str, "Ttarget= %f\tTreal= %f\n", tempTarget, getStoredTemp(temps, nextTempsIndex - 1));
			printString(str);
			// display state
			ssd1306_Fill(Black);
			sprintf(str, "Ts: %0.0f", tempTarget);
			DISPLAY_PrintStrMedium(str, 0, 0);
			sprintf(str, "Tr %0.2f", getStoredTemp(temps, nextTempsIndex - 1));
			DISPLAY_PrintStrMedium(str, 0, 11);
			sprintf(str, "Cy: %d/%d", cycleNumber, cycles);
			DISPLAY_PrintStrMedium(str, 0, 22);
			// dislay graph
			ssd1306_Line(59, 30, 127, 30, White);	// x axis
			ssd1306_Line(60, 0, 60, 32, White);	// y axis
			int limit = 0;
			if (nextTempsIndex - 1 >= 67)
				limit = 67;
			else
				limit = nextTempsIndex - 1;
			// find max and min value
			float absMax = 0;
			float absMin = 20000.0f;
			if (limit >= 2) {
				for (int x = 1; x < limit; x++) {
					if (getStoredTemp(temps, nextTempsIndex - x) > absMax)
						absMax = getStoredTemp(temps, nextTempsIndex - x);
					if (getStoredTemp(temps, nextTempsIndex - x) < absMin)
						absMin = getStoredTemp(temps, nextTempsIndex - x);
				}
				float scale = 30.0f / (2.0f + absMax - absMin);	// the scale vary according to the max and min value to display +2 for some margin
				//sprintf(str, "Graph: scale %f\t max %f\t min %f\n", scale, getStoredTemp(temps, absMaxIndex), getStoredTemp(temps, absMinIndex));
				printString(str);
				for (int x = 2; x < limit; x++) {	// take the last 50 value of temp
					uint8_t yPrev = (uint8_t) (30.0f - ((getStoredTemp(temps, nextTempsIndex - x - 1) - absMin) * scale));
					uint8_t yNow = (uint8_t) (30.0f - ((getStoredTemp(temps, nextTempsIndex - x) - absMin) * scale));
					ssd1306_Line(128 - x - 1, yPrev, 128 - x, yNow, White);
					//ssd1306_DrawPixel(128 - x, (uint8_t) (30.0f - (getStoredTemp(temps, nextTempsIndex - x) - getStoredTemp(temps, absMinIndex)) * scale), White);
				}
			}

			ssd1306_UpdateScreen();
		}
		HAL_GPIO_TogglePin(LED_ALIVE_GPIO_Port, LED_ALIVE_Pin);
		if (cycleNumber >= cycles + 1) {	// the first step is finished
			setDuty(0);	// turn of the heater
			break;
		}
	}

	// serial debug
	sprintf(str, "Measurements made %d\n", nextTempsIndex - 1);
	printString(str);
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

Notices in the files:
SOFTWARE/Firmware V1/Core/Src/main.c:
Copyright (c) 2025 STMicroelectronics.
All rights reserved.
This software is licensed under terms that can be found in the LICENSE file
